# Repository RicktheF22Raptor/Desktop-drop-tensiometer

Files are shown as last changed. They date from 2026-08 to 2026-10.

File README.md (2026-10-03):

# Open Drop Tensiometer

An open-source, low-cost **pendant drop tensiometer** — a 3D-printable, DIY alternative to commercial surface tension instruments such as the FTÅ200, built for research and educational labs that don't have **[$15,000+]** for a proprietary system.

---

## Overview

This repository contains everything needed to build, calibrate, and operate an open-source pendant drop tensiometer: mechanical designs, electronics, firmware, software, and full documentation. The instrument measures liquid surface tension by imaging a suspended droplet and fitting its shape to the Young-Laplace equation — the same principle used by commercial pendant drop systems.

Image capture and Young-Laplace analysis are performed using [OpenDrop](https://github.com/jdber1/opendrop), an existing open-source tool. This project provides the hardware platform, build documentation, and a supporting image-processing tool that improves droplet contrast for this design's optical layout.

## Motivation

Commercial pendant drop tensiometers are accurate but expensive, putting hands-on surface tension measurement out of reach for many teaching labs and small research groups. This project aims to close that gap with a fully open, reproducible instrument — see [Background](docs/background.md) for the full motivation and context.

## Features

-  Pendant drop surface tension measurement via Young-Laplace fitting
-  Fully 3D-printable frame and mounts
-  Off-the-shelf electronics
-  Built on [OpenDrop](https://github.com/jdber1/opendrop) for image capture and analysis
-  Custom contrast-enhancement tool for reliable edge detection on this hardware's optical path
-  Complete, from-scratch build and calibration documentation

## Quick Start

1. **Read the background and theory** — [Background](docs/background.md).
2. **Order parts and print components** — see the [Bill of Materials](docs/bill_of_materials.md) and [Build Instructions](docs/assembly.md).
3. **Assemble the hardware** — follow [Build Instructions](docs/assembly.md) step by step, including firmware upload and software install.
4. **Take a measurement** — follow the [Usage Guide](docs/usage.md), 

## Contributing

Contributions are welcome — bug reports, design improvements, and documentation fixes alike.

## License

This project is released under the **[license name — e.g., MIT / CERN-OHL-S / CC-BY-SA]** license. See [LICENSE](LICENSE) for the full text.

---

*Built as an open, reproducible alternative to commercial pendant drop tensiometers like the FTÅ200 — for labs and classrooms that need real measurement capability without the price tag.*

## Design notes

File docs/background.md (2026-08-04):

# Background
Surface Tension:

Surface tension is the tendency of a liquid surface to minimize its area, arising from cohesive forces between liquid molecules. Molecules at the surface experience a net inward force (since they lack neighboring molecules above them), which creates an effective "skin" that resists deformation. Surface tension is typically reported in millinewtons per meter (mN/m), equivalent to dynes per centimeter (dyn/cm).

Surface tension governs a wide range of physical and biological phenomena, including droplet formation, capillary rise, wetting behavior, foam and emulsion stability, and the spreading of coatings and inks. It is a key parameter in fields such as:

Pharmaceutical formulation (surfactant characterization, drug delivery)
Food science (emulsifiers, foams)
Materials science (coatings, adhesives, wetting agents)
Petroleum engineering (interfacial tension in enhanced oil recovery)
Biology and biochemistry (cell membrane behavior, protein adsorption)
Pendant Drop Tensiometry

Pendant drop tensiometry is one of the most widely used methods for measuring the surface or interfacial tension of a liquid. A droplet is suspended from the tip of a needle, and its shape — a balance between surface tension (which pulls the drop toward a sphere) and gravity (which elongates it) — is captured with a camera. The droplet's outline is then fit to the Young-Laplace equation to extract the surface tension.

This method has several advantages over alternatives like the Du Noüy ring or Wilhelmy plate:

Requires only a small liquid volume (microliters)
Non-invasive; no contact between a probe and the bulk liquid surface
Can measure interfacial tension between two immiscible liquids, not just liquid-air
Works across a wide range of temperatures and pressures with appropriate enclosures
Existing Commercial Instruments

Commercial pendant drop tensiometers, such as the [Biolin Scientific Attension Theta / KRÜSS DSA / TECLIS Tracker] families and the instrument this project is benchmarked against, the [FTÅ200], provide high-precision automated measurement. These systems typically include:

A precision syringe pump for controlled droplet dispensing
A high-resolution monochrome camera with telecentric or long-working-distance optics
Diffuse LED backlighting
Proprietary software for edge detection and Young-Laplace curve fitting
Cost Barriers

Commercial pendant drop tensiometers commonly range from [$15,000–$50,000+], placing them out of reach for many teaching labs, small research groups, and makerspaces. Service contracts and proprietary consumables add ongoing cost. This price point limits access primarily to well-funded industrial and academic laboratories.

Educational Accessibility

Surface tension measurement is a standard topic in physical chemistry and fluid mechanics curricula, but hands-on access to a working pendant drop tensiometer is rare outside of graduate-level research labs. An affordable, open-hardware instrument allows:

Undergraduate labs to run authentic surface tension experiments
Students to see the full measurement pipeline (optics, mechanics, image processing, curve fitting) rather than a black box
Low-resource institutions to build local capability instead of relying on shared or unavailable equipment
Motivation for an Open-Source Alternative

This project was developed to provide a low-cost, open-source pendant drop tensiometer that reproduces the core measurement capability of commercial systems such as the FTÅ200, while remaining fully documented, modular, and buildable from off-the-shelf and 3D-printed components. All mechanical designs, electronics, firmware, and analysis workflows are released openly so that the instrument can be reproduced, modified, and improved by others.

Project Objectives
Achieve surface tension measurement accuracy within [X]% of literature reference values for common calibration liquids (e.g., water, ethanol)
Keep total build cost under [$X]
Use commonly available components (3D-printed frame, off-the-shelf camera, stepper motor, microcontroller)
Provide complete, reproducible build and calibration documentation
Build on and interoperate with existing open-source analysis software (OpenDrop) rather than duplicating that work

# Working Principle

This page explains the physics behind pendant drop tensiometry before describing the hardware that implements it. For the mechanical and electrical design, see [Design Process](design.md). For step-by-step operation, see [Usage Guide](usage.md).

## 1. Surface Tension Fundamentals

Surface tension, γ, is defined as the force per unit length acting along the surface of a liquid, or equivalently the energy required to increase the surface area by one unit:

```
γ = F / L   (force per unit length, N/m)
γ = dE / dA (energy per unit area, J/m²)
```

These two definitions are dimensionally equivalent (N/m = J/m²). For most liquids of interest, γ falls in the range of roughly 15–75 mN/m at room temperature.

## 2. Pendant Drop Formation

When a liquid is dispensed slowly from a needle tip, gravity pulls the growing droplet downward while surface tension resists deformation, holding the drop together and maintaining a curved profile. The resulting droplet shape is an equilibrium between:

- **Gravitational/hydrostatic pressure**, which increases with depth in the drop and depends on liquid density
- **Laplace pressure**, the pressure difference across the curved interface, which depends on surface tension and local curvature

Because the drop is in mechanical equilibrium, its entire outline can be predicted, for a known surface tension and density, by a single differential equation — the Young-Laplace equation.

## 3. Young-Laplace Equation

The Young-Laplace equation relates the pressure difference across a curved liquid interface to its curvature and the surface tension:

```
ΔP = γ (1/R₁ + 1/R₂)
```

where R₁ and R₂ are the two principal radii of curvature at a given point on the surface. For an axisymmetric pendant drop, this reduces to a first-order ODE system describing the drop profile as a function of arc length, parameterized by:

- Surface tension, γ
- Density difference between the liquid and surrounding fluid, Δρ
- Gravitational acceleration, g
- A shape factor, β (the dimensionless "Bond number"), which captures the relative importance of gravity versus surface tension

The full derivation and numerical integration scheme (typically solved via Runge-Kutta methods) are covered in the references listed in [References](references.md). In practice, this project relies on the Young-Laplace fitting routine implemented in OpenDrop rather than re-deriving the solver, so this section focuses on how the physical setup produces the image data that solver requires.

## 4. Image Acquisition

A digital image of the pendant drop is captured with the drop backlit by a diffuse light source, producing a dark droplet silhouette against a bright, uniform background. Key requirements for a usable image:

- The needle must be vertical (perpendicular to the ground) so the drop is axisymmetric about a known axis
- The full droplet, including the point where it meets the needle tip, must be in frame
- Illumination must be uniform to avoid false edges from lighting gradients
- Sufficient contrast must exist between the drop silhouette and background (see [Image Processing](image-processing.md) for how this project addresses low-contrast conditions caused by close droplet-to-backlight spacing)

## 5. Edge Detection

The droplet boundary is extracted from the image using an edge-detection algorithm (e.g., Canny edge detection or a gradient-threshold method) that locates the transition between the dark droplet and light background at sub-pixel resolution along the length of the drop.

## 6. Curve Fitting

The extracted edge coordinates are fit to the theoretical Young-Laplace profile using a nonlinear least-squares optimization. The fitting routine adjusts γ (and other free parameters, such as the apex curvature and drop orientation) to minimize the deviation between the theoretical curve and the measured edge points.

## 7. Surface Tension Calculation

Once the best-fit Young-Laplace profile is found, the surface tension is recovered from the fitted shape factor and the known physical constants:

```
γ = Δρ · g · R₀² / β
```

where R₀ is the radius of curvature at the drop apex and β is the fitted shape factor. The pixel-to-physical-length conversion (from the [Calibration](calibration.md) procedure) and the known needle outer diameter are used to convert pixel measurements into real-world units.

## System Overview

```
Needle
  │
  ▼
Droplet ──► Image ──► Edge Detection ──► Profile Extraction ──► Young-Laplace Fit ──► Surface Tension
```

The physical components that generate each stage of this pipeline (syringe/needle, droplet, camera, backlight) are described in [Design Process](design.md).

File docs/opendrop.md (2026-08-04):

# OpenDrop Installation

This project uses **OpenDrop** to analyze pendant drop images and calculate surface tension. The hardware and additional software in this repository is designed to produce images that are compatible with OpenDrop's **Pendant Drop** analysis mode.

> **Official Documentation:**
> https://opendrop.readthedocs.io/en/latest/

---

# System Requirements

OpenDrop supports:

* Windows
* Linux
* macOS

---

# Installation

## Option 1 – Download a Release (Recommended)

1. Visit the OpenDrop GitHub releases page:

   * https://github.com/jdber1/opendrop/releases
2. Download the latest release for your operating system.
3. Install or extract the application.
4. Launch **OpenDrop**.

---

## Option 2 – Install from Source

If you wish to modify or contribute to OpenDrop, follow the installation instructions in the official documentation:

https://opendrop.readthedocs.io/en/latest/

---

# Using OpenDrop

After launching OpenDrop:

1. Select **Pendant Drop** mode.
2. Connect your USB camera to the USB port of your computer.
3. Select cv2.VideoCapture as you image source
4. select your desired number of images and capture interval
5. select "1" as your video capture source
6. Focus the camera until the droplet edge is sharp.
7. Enter the **outside diameter** of the dispensing needle.
8. Verify that the detected droplet outline matches the actual droplet.
9. Run the analysis.
10. .

---

# Image Quality Tips

For the most accurate results:

* Ensure the droplet is in sharp focus.
* Keep the camera perpendicular to the droplet.
* Avoid vibrations during image capture.

---

# Calibration

OpenDrop uses the **outside diameter of the dispensing needle** to convert image pixels into real-world dimensions.

For accurate measurements:

1. Measure or verify the needle's outside diameter.(Use a caliper for best result)
2. Enter this value into OpenDrop before analysis.
3. Confirm that the detected needle edges align with the image.(you will see a stable Yellow marker on the edge of the needle, if it is constantly shifting or or not present, adjust your needle)

Incorrect calibration will directly affect the calculated surface tension.

---

# Workflow

```text
Prepare Sample
      │
      ▼
Form Pendant Drop
      │
      ▼
Capture Image
      │
      ▼
Open in OpenDrop
      │
      ▼
Enter Needle Diameter
      │
      ▼
Verify Edge Detection
      │
      ▼
Run Analysis
      │
      ▼
Export Results
```

---

# Troubleshooting

---

# Additional Resources

* **OpenDrop Documentation:** https://opendrop.readthedocs.io/en/latest/
* **OpenDrop GitHub Repository:** https://github.com/jdber1/opendrop

For more detailed information on OpenDrop's features, supported cameras, and advanced analysis options, refer to the official documentation.

# Camera Orientation

To maximize the usable field of view, the camera is mounted in **portrait orientation** (rotated 90° clockwise or counterclockwise). Because the camera sensor is physically rotated, the video stream must also be rotated in your operating system so that the image appears upright in OpenDrop.

This configuration provides significantly more vertical image area, allowing larger pendant drops to remain in frame while maintaining the camera's full resolution.

---

## Step 1 – Rotate the Camera

Install the camera in the mount rotated **90°** from its normal landscape orientation.

Instead of this:

```text
┌────────────────────┐
│                    │
│                    │
│                    │
└────────────────────┘
Landscape
```

Mount it like this:

```text
┌────────┐
│        │
│        │
│        │
│        │
│        │
└────────┘
Portrait
```

---

## Step 2 – Rotate the Video Feed

Because the camera is now mounted sideways, the image will also appear sideways until it is rotated in software.

### Windows 11

Windows 11 can rotate the video stream from many USB (UVC) cameras.

1. Open **Settings**.

2. Navigate to **Bluetooth & devices → Cameras**.

3. Select your USB camera.

4. Under **Video rotation**, select:

   * **Right 90°** or
   * **Left 90°**

   Choose the option that makes the needle vertical.

5. Close and reopen OpenDrop if it was already running.

> **Note:** The **Video rotation** option is only available if the camera and its driver support this feature. Windows stores this setting for the selected camera and automatically applies it whenever supported applications access the camera.

---

### macOS

macOS does **not** provide a system-wide rotation setting for external USB webcams.

If your camera is mounted in portrait orientation, you have two options:

#### Option 1 (Recommended)

Rotate the image using the camera manufacturer's software, if available.

#### Option 2

Use a virtual camera application such as **OBS Studio**:

1. Add the USB camera as a **Video Capture Device**.
2. Right-click the camera source.
3. Select **Transform → Rotate 90° Clockwise** (or Counterclockwise).
4. Start the **OBS Virtual Camera**.
5. Select **OBS Virtual Camera** as the camera source in OpenDrop (if your version supports virtual cameras).

If you are capturing still images outside of OpenDrop, simply rotate the image before importing it for analysis.

---

## Verify Orientation

Before beginning any measurements, confirm that:

* ✅ The needle is perfectly vertical.
* ✅ The droplet hangs straight downward.
* ✅ The entire droplet fits within the image.
* ✅ The needle tip is near the top of the frame.
* ✅ There is sufficient space below the droplet for larger drops.
* ✅ The droplet is sharply focused.

A correctly configured image should appear similar to the example below:

```text
        Needle
          │
          │
          ▼
         ( )
        (   )
       (     )
        (   )
         ( )
```

A correctly rotated image maximizes the vertical field of view and allows larger droplets to be analyzed without sacrificing image resolution.

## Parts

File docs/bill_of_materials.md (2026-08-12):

# Bill of Materials (BOM)

This project is built using readily available, off-the-shelf components. Unless otherwise noted, equivalent parts may be substituted.

---

## Core Components

| Item | Qty | Description | Link |
|---|:---:|---|---|
| Arducam 2 MP Global Shutter USB Camera (OV2311) | 1 | Monochrome global shutter camera used to capture droplet images. The global shutter eliminates motion distortion and improves edge detection. | https://www.arducam.com/arducam-2mp-global-shutter-usb-camera-board-for-computer-50fps-ov2311-monochrome-uvc-webcam-module-with-low-distortion-m12-lens-without-micro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 |
| Adafruit LED Backlight (#4882) | 1 | Uniform LED backlight for creating a high-contrast droplet silhouette. | https://www.adafruit.com/product/4882 |
| ElectroCookie Large Protoboard | 1 | Solderable prototyping board used for power distribution and permanent wiring. | https://www.amazon.com/dp/B081MSKJJX |
| Assorted resistor set| 1 | Solderable resisters, you need a 120-150 ohm resistor for |https://www.amazon.com/LuminologyPro-1000-Piece-Resistor-25-Value-1Ω-1MΩ/dp/B0F4P352BB/ref=sr_1_4?channelId=500&clpRedir=Y&dib=eyJ2IjoiMSJ9.QqtzmCG7CKt6OW1fHgTb26zvfysLYHBppMF-8-2hzsK1qR2DXLeIZ96O4s7YoxaWuzCqvr_Bgi_G-IGcD_N-UycOiRW7sG5AlogNWxSyNIjHzjx6gTXWZKJyEfUiyq529LsZNc_RYvqIgvvNUj6Y-eQiuirJ3k670EWui9-3fRJPoLjuW-hKM5K_VcSlcDWWNrF0RyaBiyOF0E3TJpn6j45dyGgfTfYa8ET67Bwpya0.V9iNics_qiNHfrL4BESLDFV3l2iiWk1OA2DY5eHRMgg&dib_tag=se&keywords=resistor+kit&plpRedirect=mhFallback&qid=1786494608&sr=8-4 |
|Potentiometer set | 1 | Solderable resisters, one of these is needed for controlling the brightness of the LED| https://www.amazon.com/BOJACK-Variable-Resistor-Potentiometer-Assortment/dp/B07WHJMVR4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|

---

## Wiring & Connectors

| Item | Qty | Description | Link |
|---|:---:|---|---|
| 22 AWG Silicone Wire Kit | 1 | Flexible stranded wire for power and signal wiring. | https://www.amazon.com/s?k=22+awg+silicone+wire |
| Dupont Connector Kit | 1 | Female and male crimp connectors for removable signal connections. | https://www.amazon.com/s?k=dupont+connector+kit |
| JST-XH Connector Kit | 1 | Locking connectors for power and LED wiring. | https://www.amazon.com/s?k=jst+xh+connector+kit |
| Assorted JST-XH Crimp Pins | 1 | Replacement crimp pins for JST connectors. | https://www.amazon.com/s?k=jst+xh+crimp+pins |
| Heat Shrink Tubing Kit | 1 | Insulates solder joints and protects wiring. | https://www.amazon.com/s?k=heat+shrink+tubing+kit |

---

## Notes

- Equivalent parts from other manufacturers can generally be substituted.
- M3 hardware is used throughout the design unless otherwise noted.
- OpenDrop is free and open-source software and is **not** included in the hardware BOM.
- 3D printed parts are provided in the `/CAD` directory of this repository.

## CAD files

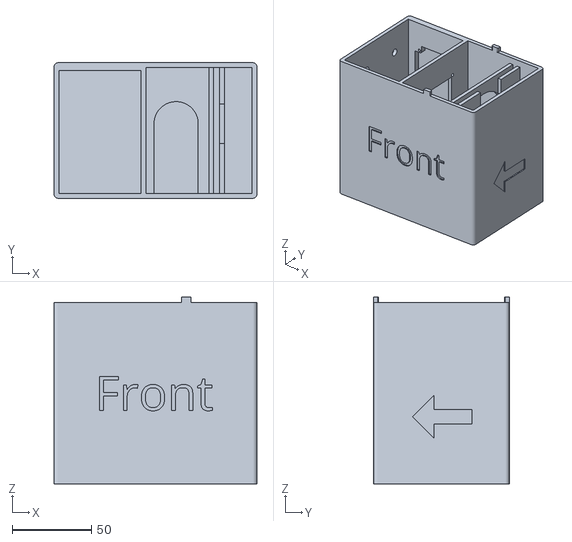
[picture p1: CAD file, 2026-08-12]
Tensiometer parts/main plate.stl
128.0 x 85.5 x 117.8

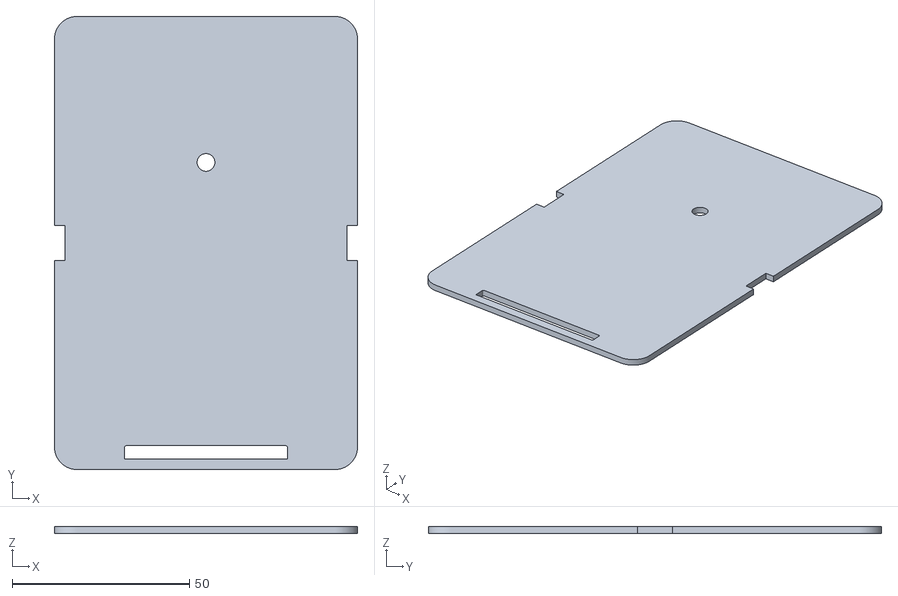
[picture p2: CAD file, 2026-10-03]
Tensiometer parts/V2 tensiometer/Test tensiometer - V2 lid.stl
85.5 x 127.8 x 2.00

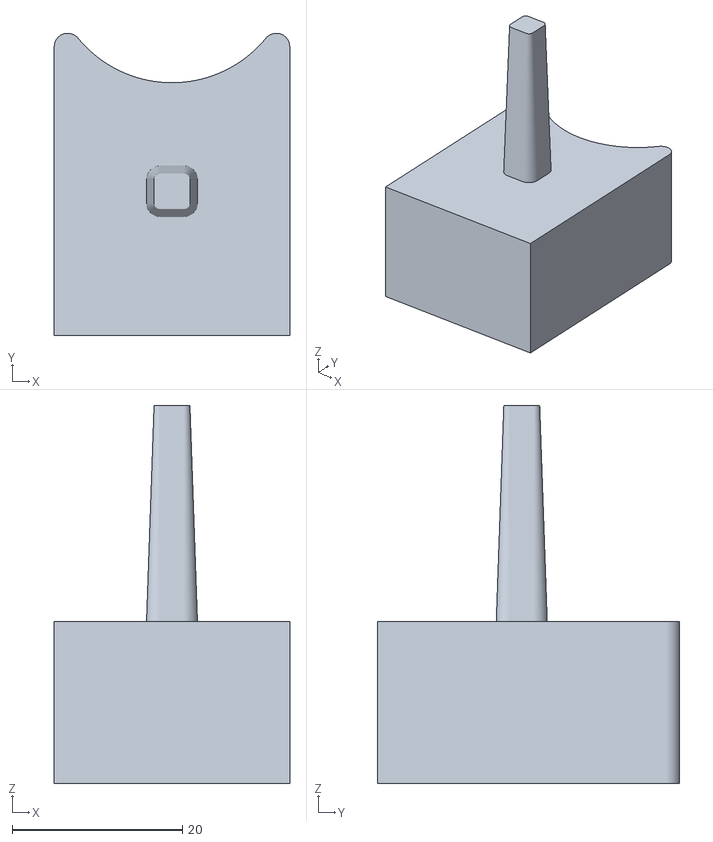
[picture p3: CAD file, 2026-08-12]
Tensiometer parts/vial stopper.stl
27.7 x 35.6 x 44.4

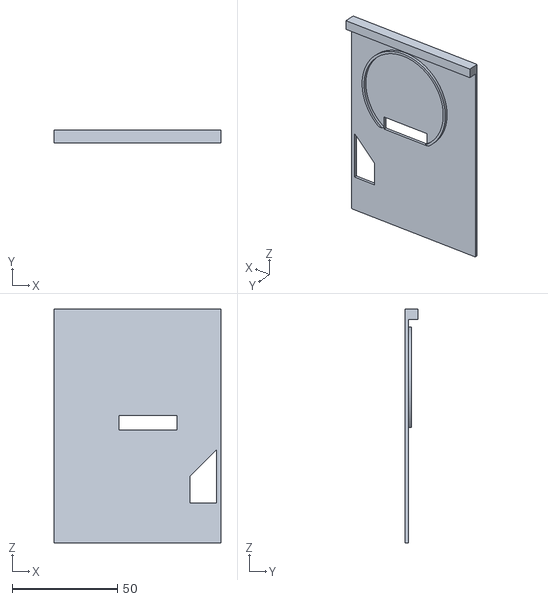
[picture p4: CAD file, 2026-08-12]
Tensiometer parts/Light holder.stl
79.2 x 5.97 x 111.3

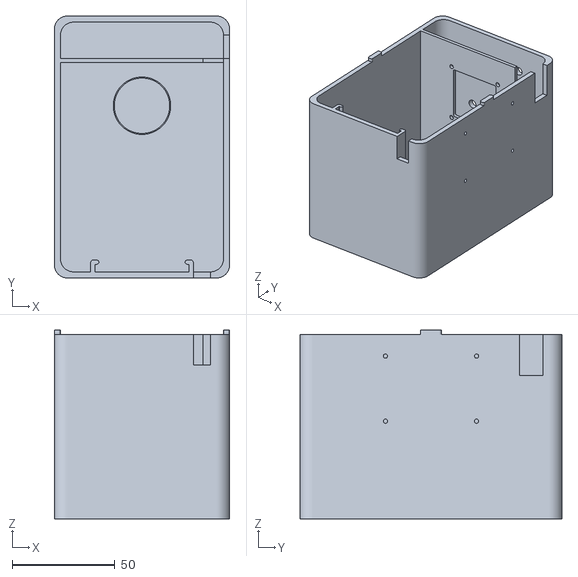
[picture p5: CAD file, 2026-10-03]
Tensiometer parts/V2 tensiometer/Test tensiometer - V2 plate.stl
85.5 x 127.8 x 92.0

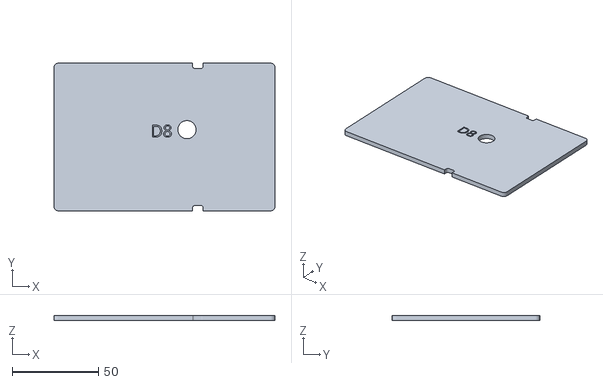
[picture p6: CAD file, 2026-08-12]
Tensiometer parts/Lid.stl
128.0 x 85.5 x 3.00

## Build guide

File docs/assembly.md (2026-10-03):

# Assembly Guide
---

# Electronics set up:

# USB Camera + Switch/Potentiometer-Controlled LED — Wiring Guide

A single protoboard hosts a USB-connected camera and an on/off, potentiometer-dimmed LED, both powered from the same USB 5V/GND source.

## Parts

| Part | Link | Notes |
|---|---|---|
| Arducam 1080P USB2 UVC camera module | [product page](https://www.arducam.com/arducam-1080p-ultra-low-light-100-degree-wide-angle-usb2-uvc-camera-module.html) | 5V, ~1W max, UVC plug-and-play |
| 6mm trimmer potentiometer, 500Ω | [BOJACK 15-value assortment kit](https://www.amazon.com/BOJACK-Variable-Resistor-Potentiometer-Assortment/dp/B07WHJMVR4) | Use the "501" (500Ω) value from the kit |
| On-Off-On-Off alternating pushbutton | [Adafruit #1684](https://www.adafruit.com/product/1684) | 3-pin momentary switch; only common + one side used (see note below) |
| Round LED backlight, 50mm | [Adafruit #4882](https://www.adafruit.com/product/4882) | ~3V @ 20mA, needs a series resistor |
| ElectroCookie solderable protoboard | [Amazon listing](https://www.amazon.com/ElectroCookie-Solderable-Breadboard-Electronics-Gold-Plated/dp/B081MSKJJX) | Standard breadboard hole pattern |
| 150Ω resistor, 1/4W, 5% | Not linked — any standard 150Ω, 1/4W resistor works | Current limiter for the LED |

**Tools:** soldering iron + solder, wire strippers, a few short jumper wires, a multimeter (for verifying VCC/GND before powering up).

## How the circuit works

```
USB (computer)
   │
   ├── 5V / GND / D+ / D−  →  camera (data + power, untouched)
   │
   └── 5V → potentiometer (500Ω) → resistor (150Ω) → switch → LED → GND
```

The camera branch and the LED branch both pull from the same USB 5V/GND — they share power but not any other connection, so nothing on the LED side can interfere with the camera's data lines.

**Current calculation:**
```
I = (V_supply − V_LED) / (R_pot + R_fixed)
V_supply = 5V,  V_LED ≈ 3V,  R_fixed = 150Ω

Pot = 0Ω (brightest):  I = 2V / 150Ω  = 13.3 mA
Pot = 500Ω (dimmest):  I = 2V / 650Ω  ≈ 3.1 mA
Switch open:           I = 0 mA (LED off, regardless of pot position)
```

**Note on the switch:** the #1684 pushbutton cycles through 4 states per repeated presses (side A on → off → side B on → off). Only the common pin and one side pin are wired here. Practical effect: from "on," a single press always turns the LED off. From "off," it can take up to a few extra presses to cycle back to "on," since the switch is also passing through its unused side. It's a reliable off-switch; just not a perfectly symmetric single-press toggle.

## Step-by-step wiring

Breadboard numbering: columns `1, 2, 3…`, rows `A–E` (top half) and `F–J` (bottom half). Holes in the same column and same half are already tied together inside the board. The two halves only connect where you add a jumper across the center gap.

1. **Land the USB cable's 4 wires in columns 1–4, row A.**
   - VCC (red) → `A1`
   - GND (black) → `A2`
   - D+ → `A3`
   - D− → `A4`

2. **Run the camera's 4 leads into the same columns, row E** (so each camera lead shares a column — and therefore a net — with its matching USB wire):
   - Camera VCC → `E1`
   - Camera GND → `E2`
   - Camera D+ → `E3`
   - Camera D− → `E4`

3. **Add the two power jumpers**, crossing from the top half to the bottom half:
   - VCC jumper: `B1` → `H5`
   - GND jumper: `B2` → `F2`

4. **Place the potentiometer.** Its 3 legs form a triangle (round trimmer body), not a straight line:
   - Outer leg 1 → `F5` (lands on the VCC jumper's column)
   - Outer leg 2 → `F7` (leave unconnected)
   - Wiper (middle, set back one row) → `G6`

5. **Place the resistor**, bridging from the wiper's column to a fresh column:
   - Lead 1 → `H6` (same column as the wiper)
   - Lead 2 → `H9`

6. **Place the switch**, using only the common pin and one throw pin:
   - Throw pin A → `F9` (same column as resistor lead 2)
   - Common pin → `F11`
   - Other throw pin → leave unconnected, bend it out of the way

7. **Place the LED:**
   - Anode → `G11` (same column as the switch's common pin)
   - Cathode → `G2` (same column as the GND jumper)

8. **Double-check before powering on** (see Verification below), then plug the USB cable into your computer.

## Verification

- With a multimeter, confirm ~5V between `A1`/`E1` and `A2`/`E2` before connecting anything else — this confirms you've identified VCC/GND correctly on the USB wires.
- Check for continuity between `A1` and `H5` (should show the VCC jumper), and between `A2` and `F2` (GND jumper).
- Check there is **no continuity** between column 1–4 (camera/USB zone) and columns 5–11 (LED zone) except through the two jumpers — this confirms the two branches aren't accidentally shorted together.
- Plug in the camera — it should enumerate as a UVC webcam with no driver install needed.
- Turn the pot — LED brightness should sweep smoothly from dim to bright.
- Press the switch — LED should turn off from any brightness level.

## Full hole position reference

| Component | Position | Net |
|---|---|---|
| USB VCC | `A1` | VCC |
| USB GND | `A2` | GND |
| USB D+ | `A3` | D+ |
| USB D− | `A4` | D− |
| Camera VCC | `E1` | VCC |
| Camera GND | `E2` | GND |
| Camera D+ | `E3` | D+ |
| Camera D− | `E4` | D− |
| VCC jumper | `B1` → `H5` | VCC |
| GND jumper | `B2` → `F2` | GND |
| Pot outer leg 1 | `F5` | VCC |
| Pot outer leg 2 | `F7` | unconnected |
| Pot wiper | `G6` | Wiper |
| Resistor lead 1 | `H6` | Wiper |
| Resistor lead 2 | `H9` | R-out |
| Switch throw A | `F9` | R-out |
| Switch common | `F11` | Switched |
| LED anode | `G11` | Switched |
| LED cathode | `G2` | GND |

## Design notes

- **Camera and LED branches use entirely separate columns** (1–4 vs. 5–11) so a stray probe or wire can't accidentally bridge an unrelated net.
- **Only 2 jumpers are used**, because only VCC and GND need to reach the bottom half — the USB data lines (D+/D−) stay entirely within the top half between the USB cable and the camera, so they never need to cross the gap.
- **Component order (pot → resistor → switch → LED) doesn't change the math** — it's a series loop, so total resistance and current are the same regardless of order. The resistor sits right before the LED so the safety-critical current limit stays physically close to the part it's protecting.
- **The pot's wiper lands one row below its outer legs** (`G6` instead of the same row as `F5`/`F7`) because the round trimmer's wiper pin is physically set back from the two front legs — the hole map follows the part's real shape rather than forcing it into a straight line.

## Build notes

- Total current draw (camera ~200mA + LED ~13.3mA max) is well within a single USB port's supply — no second port or external power needed.
- The pushbutton's leads aren't on a perfect 0.1" grid — bend them slightly to seat cleanly in `F9`/`F11`.
- Solder power connections securely; a loose VCC/GND joint interrupts power to the camera as well as the LED branch, since both share the same jumpers.

# Procedure(V1)
### 1. After printing all of the parts, use the light holder and place the LED in the circular slot, make sure the leads go through the other side 


### 2. Use 4 m2.5 screws and nuts to secure the usb camera, ensure that the connector is place vertically on the left or right, a 90 degree rotation from the standard position)


### 3. Follow the electronics assembly instructions, mount the board to the apparatus, using 4 m2 screws on each corner tot the inside back wall in the camera chamber.


### 4. Place lid on the apparatus and procced with usage guide


# Procedure (V2)

V2 uses a different light source and resistor value, which provides sufficient droplet/background contrast directly — no image processing step is required before analysis. Electronics, mounting hardware, and general assembly are otherwise identical to V1 except where noted below. The wiring diagram can be followed as previously described by switiching out the resistor.

Parts that differ from V1:

Part	Link	Notes
[V2 light source]	[[link]](https://www.adafruit.com/product/1621)]	[voltage/current spec]
[V2  100 ohms resistor value]	[https://www.amazon.com/BOJACK-Resistor-Ohm-5-6M-Resistors-Assortment/dp/B07P3MFG5D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]	[what it's current-limiting]

Steps:

### 1. After printing all of the parts, Place the assembled electronics inside the plate making sure it securely screwed in, with all components connected piror to installation


### 2. Use 4 m2.5 screws and nuts to secure the usb camera, ensure that the connector is place vertically on the left or right, a 90 degree rotation from the standard position)


### 3. Place light in vertical slot with wires pointing up as they will be threaded through the lid slot 


### 4. Place the lid and connect wires for the ligh tthrought the hole in the side and procced with usage guide.


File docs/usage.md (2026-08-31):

# Usage Guide

This guide covers day-to-day operation of the instrument using **[OpenDrop](https://github.com/jdber1/opendrop)**, the open-source software this project uses for image capture, edge detection, and Young-Laplace fitting. It assumes the hardware is already built ([Build Instructions](assembly.md)).

## Before You Start

- Confirm calibration is still valid for your current camera/needle setup.
- Have your sample liquid prepared and the syringe loaded with air bubbles cleared.

## 1. Launch OpenDrop and Connect the Camera

1. Open OpenDrop.
2. Select the **Live Video** option as your image source.
3. Choose your camera — this is usually **1**
4. Confirm a live preview appears before continuing.

## 2. Set Up Camera Orientation

To maximize the usable field of view, the camera in this design is mounted in **portrait orientation** (rotated 90° from its default landscape orientation). Because most USB cameras natively capture in landscape, the video stream needs to be rotated in your OS so it appears upright in OpenDrop.

**Windows 11**

1. Open **Settings → Bluetooth & devices → Cameras**.
2. Select your USB camera.
3. Under **Video rotation**, choose **Right 90°** or **Left 90°** — whichever makes the needle appear vertical in OpenDrop's preview.
4. Close and reopen OpenDrop if it was already running.

> If the **Video rotation** option isn't available, your camera/driver doesn't support it — use the macOS/alternative method below instead.

**macOS**

macOS has no built-in rotation setting for external USB webcams. Options, in order of preference:

1. Use the camera manufacturer's software to rotate the stream, if it offers one.
2. Use **OBS Studio** as a virtual camera: add the USB camera as a Video Capture Device, right-click it → **Transform → Rotate 90°**, start the **OBS Virtual Camera**, then select it as the source in OpenDrop (if your OpenDrop version supports virtual camera sources).
3. If capturing still images outside OpenDrop entirely, rotate them before importing.

**No software rotation available**

Rotate the camera physically 90° in its mount instead, so the sensor itself captures portrait images.

**Verify before continuing** — in the OpenDrop preview, confirm:

- ✅ Needle is perfectly vertical
- ✅ Needle tip is near the top of the frame
- ✅ There's enough space below the needle for the droplet to grow into
- ✅ Image is in focus

## 3. Frame the Needle

1. Adjust the camera mount (or reposition the frame) so the needle is horizontally centered in the OpenDrop preview.
2. Confirm the full expected droplet size will fit within the frame — grow a test droplet if unsure, then retract it before your real measurement.

## 4. Set Up a New Measurement in OpenDrop

1. In OpenDrop, start a new **Pendant Drop** experiment/project.
2. Enter the needle's measured outer diameter when prompted for the reference length. OpenDrop uses this to convert pixel measurements to physical units.

## 5. Set Image Count and Interval

Before capturing, set how many images OpenDrop should take and the time interval between them:

1. Set the **number of images** to capture — a single image is enough for a static measurement; capture a series (with an interval) if you want to track surface tension over time (e.g., for surfactant adsorption studies).
2. Set the **interval** between images (in seconds).
3. Slowly advance the syringe plunger (manually, or via the motorized stage if installed) until a droplet forms at the needle tip, and let it settle before starting capture — a droplet that's still growing or oscillating won't represent true equilibrium and will bias the fit.

## 6. Improve Contrast, If Needed

Because this hardware places the droplet close to the LED backlight for even illumination, raw images often have lower droplet-to-background contrast than commercial systems produce. As a result, the droplet may appear light gray rather than nearly black, which can cause OpenDrop's edge detection to struggle once you run the analysis (step 7).

If this happens, run your images through the contrast-enhancement tool before analyzing:

1. Save your captured image(s) from OpenDrop.
2. Upload the saved image(s) to the image processing tool (**[hosted at: URL, or run locally from `tools/image-processor/`]**).
3. Wait for processing to complete, then download the processed images.
   - The tool increases contrast between the droplet and background and darkens the droplet silhouette, while preserving the true droplet geometry — no geometric transformations or scaling are applied, so the droplet shape used for the fit is unaffected.
   - The result should show a noticeably darker droplet silhouette against a brighter, more uniform background, similar to the high-contrast examples in the OpenDrop documentation.
4. In OpenDrop, open the processed image(s) in place of the originals.
5. Continue to step 7 to run the analysis.

This contrast-enhancement step is a normal part of the workflow for this hardware, not a workaround — treat it as **Capture → Enhance → Analyze** whenever raw contrast looks low.

## 7. Run the Analysis

This is the easy part — OpenDrop handles edge detection and the Young-Laplace fit together behind a single **Analyze** button.

1. Click **Analyze**.
2. OpenDrop detects the droplet edge, fits it to the Young-Laplace profile, and reports the surface tension along with the fitted profile overlaid on the image.
3. Visually check that the overlaid fit tracks the actual droplet outline along its full length, not just near the apex. If it doesn't — or if OpenDrop flags a poor fit — the usual causes are low contrast, poor focus, or the needle/droplet being out of frame; see [Troubleshooting](troubleshooting.md), and step 6 above if contrast looks like the issue.

## 8. Save the Results

1. Use OpenDrop's save/export function to save the results (surface tension value, and image series results if you captured more than one image).
2. Save alongside the liquid identity, temperature, and date for your own records — OpenDrop won't capture this context automatically.
3. Keep exported results in [`Data/`](../Data/) for your records.
4. For a first-time setup or after any recalibration, run this full workflow on distilled water and compare against the literature value (72.8 mN/m at 20 °C) before trusting results on unknown samples — see [Calibration → Baseline Validation](calibration.md#baseline-validation).

## Quick Reference

```
Launch OpenDrop → Live Video → select camera (usually Camera 1) → check orientation
   → frame needle → set image count + interval → generate droplet → capture
   → Analyze → [enhance contrast + re-analyze if needed] → Save results
```

For hardware assembly, see [Build Instructions](assembly.md). For the physics behind the fit, see [Working Principle](theory.md). For anything that isn't working as expected, see [Troubleshooting](troubleshooting.md).
